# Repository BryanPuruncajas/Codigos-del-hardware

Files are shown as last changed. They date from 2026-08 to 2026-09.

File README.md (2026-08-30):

# mi-blimp-mio — Manual técnico completo del proyecto de tesis

**Estado revisado:** 30 de agosto de 2026  
**Plataforma principal:** Seeed Studio XIAO ESP32-S3  
**Comunicación de tierra:** ESP32 Base Station por USB ↔ ESP-NOW ↔ XIAO ESP32-S3  
**Visión:** Arduino Nicla Vision con OpenMV/MicroPython  
**Sensores activos:** BNO085/BNO086 + BMP390 + batería + Nicla Vision  
**Actuadores:** 2 motores brushless con ESC + 2 servos K-Power P0025  
**Control:** por consola (`run_test.py`) o desde la app móvil **AeroStock** (`blimp_app/`)

---

## Guía rápida: cómo correr todo hoy

Esta sección es el punto de entrada para un día de pruebas. El detalle de cada
prueba (P00–P11, parámetros, teoría) sigue más abajo en las secciones
numeradas; esto es solo la secuencia de arranque.

### Paso 0 — una sola vez

```powershell
# Firmware (necesita PlatformIO CLI instalado)
cd firmware
pio run

# Ground station (Python)
cd ../groundstation
pip install -r requirements.txt

# App AeroStock (solo si vas a compilarla vos; si ya está instalada en el
# celular, salteá esto)
cd ../blimp_app
flutter pub get
```

### Paso 1 — subir firmware

```powershell
cd firmware
pio run -t upload
pio device monitor -b 115200   # anotá la MAC que imprime al bootear
```

```powershell
cd ../base_station
pio run -t upload
pio device monitor -b 115200   # anotá la MAC de la base (BASE_MAC,...)
```

### Paso 2 — configurar `groundstation/user_parameters.py`

```python
robot_macs = ["AA:BB:CC:DD:EE:FF"]   # la MAC que imprimió el XIAO
SERIAL_PORT = "COM7"                 # el COM de la BASE STATION, no el del XIAO
```

Esto lo usan **tanto** `run_test.py` como `telemetry_bridge.py` (la app usa este mismo archivo).

### Paso 3A — controlar por consola

```powershell
cd groundstation
python run_test.py p01 --seconds 30
```

Ver la sección **23. run_test.py** más abajo para la lista completa de pruebas y parámetros.

### Paso 3B — controlar desde la app AeroStock

1. Cerrá cualquier Monitor Serial abierto (Arduino/PlatformIO) — si no, el bridge no puede abrir el COM.
2. Arrancá el bridge:
   ```powershell
   cd groundstation
   python telemetry_bridge.py COM7
   ```
   Sin `--dev-token` usa `changeme` por default, que es el mismo valor que trae
   "quemado" `AppConfig.devToken` en la app — no hace falta que coincidas nada a mano.
   Vas a ver en consola dónde está grabando el CSV de esta corrida.
3. Conseguí la IP de la laptop (`ipconfig`, buscá la IPv4 de la red WiFi). El celular tiene que estar en la **misma red**.
4. En la app: **Modo desarrollador** → ícono de red (⚙️) → poné la IP → **Conectar**. El chip de arriba tiene que decir **"Dev"** (si dice "solo viewer", el token no coincide).
5. Paneles disponibles en Modo desarrollador:

   | Panel | Equivale a | Para qué |
   |---|---|---|
   | **Misión** | `run_test.py p08/p09/p10/p11` | Lanzar una misión completa (armado automático + parámetros) |
   | **Panel de control** | `run_test.py p04/p05` | Altura sola / altura+yaw |
   | **Control manual** | `run_test.py p02` | D-pad: mantener presionado mueve, soltar vuelve a neutro |
   | **Banco de pruebas** | `run_test.py p00` / `p00m` | Servos sueltos (con presets Vertical/Avance/Retroceso) y motores con potencia manual, con confirmación explícita antes de armar brushless |

   Las gráficas de altura/yaw en vivo (actual vs referencia) y el track de
   globos visitados están siempre visibles arriba de estos paneles.
6. **Sin hardware a mano:** desde el home, "Vista previa (demo)" recorre toda
   la interfaz con datos simulados — útil para mostrar la app o revisar un
   diseño sin encender nada.

El CSV se graba automático en `logs/` tanto si controlás por consola como por
la app — mismo formato en los dos casos, `python analyze.py <archivo>.csv` funciona igual.

---

## 1. Objetivo del proyecto

El proyecto controla un blimp/bicóptero de tesis capaz de:

1. medir altura, orientación y velocidad angular;
2. recibir detecciones visuales desde una Nicla Vision;
3. controlar dos motores brushless y dos servos tilt;
4. comunicarse con una estación base por ESP-NOW;
5. ejecutar pruebas incrementales P00–P11;
6. evolucionar hacia una misión autónoma de visita de **4 globos visualmente idénticos**.

La filosofía actual es validar primero cada subsistema de forma aislada y luego combinarlos.

---

# 2. Estructura del repositorio

```text
mi-blimp-mio/
├── README.md
├── CHANGELOG.md
├── base_station/
│   ├── platformio.ini
│   └── src/main.cpp
├── calibration/
│   ├── gaussian_manual.py
│   ├── gaussian_manual_multi.py
│   └── colors/
│       ├── red.txt
│       └── purple.txt
├── docs/
│   ├── ARCHITECTURE.md
│   ├── PROJECT_TREE.txt
│   └── TEST_SEQUENCE.md
├── firmware/
│   ├── platformio.ini
│   ├── src/
│   │   ├── main.cpp
│   │   ├── app/
│   │   ├── mission/
│   │   └── tests/
│   └── lib/BlimpSwarm/
├── groundstation/
│   ├── run_test.py
│   ├── user_parameters.py
│   ├── common/
│   └── tests/
├── legacy/
├── logs/
└── vision/
    ├── get_gains.py
    └── perception_subsystem.py
```

### Carpetas importantes

| Carpeta | Función |
|---|---|
| `firmware/` | Firmware del XIAO ESP32-S3 montado en el blimp. |
| `base_station/` | Firmware de la ESP32 conectada al PC por USB. |
| `groundstation/` | Scripts Python para mandar comandos, armar, ejecutar pruebas y guardar telemetría. |
| `vision/` | Código MicroPython/OpenMV de la Nicla Vision. |
| `calibration/` | Datos y scripts para calibración estadística de colores. |
| `logs/` | CSV generados automáticamente por `run_test.py` o `telemetry_bridge.py` (mismo formato). |
| `mission/` | Máquina de estados P08–P11. |
| `legacy/` | Código heredado/no activo conservado como referencia. |

---

# 3. Hardware del blimp

## 3.1 XIAO ESP32-S3

El firmware principal utiliza:

```ini
[env:seeed_xiao_esp32s3]
platform = espressif32
board = seeed_xiao_esp32s3
framework = arduino
monitor_speed = 115200
upload_speed = 921600
```

Dependencias principales:

- ESP32Servo
- IBusBM
- Adafruit BMP3XX
- Adafruit BusIO
- Adafruit Unified Sensor
- SparkFun BNO08x Arduino Library

---

## 3.2 Pinout actual

Fuente: `firmware/src/app/AppConfig.h`.

| Función | Pin XIAO S3 |
|---|---:|
| Servo 1 | D0 |
| Servo 2 | D1 |
| RST BNO085/BNO086 | D2 |
| I2C SDA | D4 |
| I2C SCL | D5 |
| Nicla TX esperado | D6 |
| Nicla RX esperado | D7 |
| ADC batería | D8 |
| Brushless / ESC 1 | D9 |
| Brushless / ESC 2 | D10 |

### D2

`D2` está reservado para el reset del BNO.

Al arrancar:

```cpp
pinMode(D2, OUTPUT);
digitalWrite(D2, HIGH);
```

No reutilizar D2 para servos, motores u otra señal.

---

# 4. Calibración física de servos y vectores de empuje

Servos utilizados: **K-Power P0025**.

Configuración nominal:

| Ángulo lógico | PWM |
|---:|---:|
| 0° | 900 µs |
| 60° | 1500 µs |
| 120° | 2100 µs |

Conversión activa:

```text
0..120°  <=>  900..2100 µs
```

## 4.1 Orientaciones físicas validadas

Estas posiciones ya fueron probadas físicamente:

| Movimiento | Servo 1 | Servo 2 |
|---|---:|---:|
| Vector vertical +Z | 35° | 95° (era 85°, corregido el 23/08 por desalineación de la góndola izquierda) |
| Avance | 120° | 0° |
| Retroceso | 0° | 120° |
| Giro derecha / horario | 120° | 120° |
| Giro izquierda / antihorario | 0° | 0° |

Vista frontal usada durante las pruebas:

- Servo 1: lado izquierdo.
- Servo 2: lado derecho.

Convención de yaw observada físicamente:

- giro horario → yaw disminuye;
- giro antihorario → yaw aumenta;
- yaw trabaja en radianes dentro del firmware y envuelve en `[-π, +π]`.

---

# 5. Motores brushless y ESC

## 5.1 Escala de potencia actual

**Importante:** el código fuente actual tiene:

```cpp
ABSOLUTE_MOTOR_POWER_LIMIT = 1.00f;
motorPowerLimit = 1.00f;
```

Por tanto:

```text
0.00 = 0 %
0.10 = 10 %
0.20 = 20 %
1.00 = 100 % de la escala heredada
```

La documentación vieja que dice “límite duro de 50 %” está desactualizada.

## 5.2 Configuración de los ESC

En `RawBicopter::startup()`:

```cpp
motor1 = new BLMotor(1100, 2000, 0, D9, 55);
motor2 = new BLMotor(1100, 2000, 0, D10, 58);
```

La secuencia de ARM reproduce el comportamiento efectivo del firmware viejo:

1. habilita servos y ESC;
2. manda throttle mínimo;
3. mantiene aproximadamente throttle mínimo durante ~3.7 s;
4. termina con motores en 0 %;
5. recién después `actuatorsArmed = true`.

No existe auto-arm al encender.

---

# 6. Seguridad de arranque

Al boot:

- D2 se pone HIGH para liberar el BNO.
- pines de motores y servos comienzan en alta impedancia;
- los actuadores permanecen desarmados;
- no se ejecuta calibración automática de ESC;
- para mover motores se necesita un ARM explícito.

`SAFE_STOP` tiene modo `0`.

Cuando `run_test.py` termina o recibe `Ctrl+C`, intenta:

```text
STOP + DISARM
```

enviando varias veces el modo seguro.

> Seguridad eléctrica: el software no evita por sí mismo un posible backfeed desde USB/rail de alimentación. Verificar alimentación físicamente cuando se trabaja con batería desconectada.

---

# 7. Sensores del XIAO ESP32-S3

## 7.1 BMP390

El BMP390:

- usa I2C;
- oversampling temperatura: 8X;
- oversampling presión: 16X;
- filtro IIR: coeficiente 7;
- ODR configurado: 100 Hz;
- la rutina de actualización efectiva limita lecturas aproximadamente a 50 Hz (`20 ms`).

### Calibración de cero de altura al boot

Al iniciar:

1. descarta 5 lecturas;
2. toma 10 lecturas;
3. promedia la altitud barométrica;
4. guarda ese promedio como `groundLevel`.

La telemetría de altura es:

```text
altura = altitud barométrica - groundLevel
```

Por eso cada reinicio redefine el cero barométrico.

La velocidad vertical se calcula a partir del cambio de altitud y luego SensorSuite aplica suavizado.

---

## 7.2 BNO085/BNO086

Bus I2C:

```text
SDA = D4
SCL = D5
RST = D2 HIGH
I2C = 400 kHz después de conectar
```

### Dirección configurada actualmente

El código intenta:

```cpp
myIMU.begin(0x4A, Wire)
```

Por tanto el firmware actual espera **0x4A**.

Si el módulo físico está configurado a `0x4B`, este código debe modificarse o el sensor no será detectado.

### Datos utilizados

El firmware usa el reporte:

```text
Gyro Integrated Rotation Vector
```

y obtiene:

- roll;
- pitch;
- yaw;
- velocidad angular X;
- velocidad angular Y;
- velocidad angular Z.

---

# 8. Mapa completo de sensores

`SensorMap.h`:

| Índice | Variable |
|---:|---|
| 0 | temperature |
| 1 | altitude |
| 2 | vertical_velocity |
| 3 | roll |
| 4 | pitch |
| 5 | yaw |
| 6 | roll_rate |
| 7 | pitch_rate |
| 8 | yaw_rate |
| 9 | reservado |
| 10 | battery |
| 11 | nicla_flag |
| 12 | nicla_x |
| 13 | nicla_y |
| 14 | nicla_w |
| 15 | nicla_h |
| 16 | nicla_x_value |
| 17 | nicla_y_value |
| 18 | nicla_w_value |
| 19 | nicla_h_value |
| 20 | nicla_distance |

No existe ultrasonido en la ruta activa actual.

---

# 9. Nicla Vision

## 9.1 Qué hace realmente el “entrenamiento”

Actualmente **no se entrena una red neuronal**.

La detección de globos usa:

- imagen RGB565;
- espacio de color LAB;
- grilla 14 × 21;
- estadísticas de `A` y `B`;
- modelo gaussiano 2D;
- distancia de Mahalanobis;
- filtro probabilístico por celdas;
- seguimiento temporal.

El proceso llamado “entrenamiento” en este proyecto consiste en:

1. capturar muchos pares `(A, B)` del color del globo;
2. calcular media;
3. calcular matriz de covarianza;
4. invertir la covarianza;
5. copiar la media y matriz inversa a `COLOR_DATA`.

---

## 9.2 Configuración actual de imagen

En `vision/perception_subsystem.py`:

```python
FRAME_SIZE = sensor.HQVGA
```

Para Nicla:

```text
240 × 160 px
```

Centro horizontal usado por el control:

```text
x_center = 120 px
```

Grilla:

```text
N_ROWS = 14
N_COLS = 21
```

Objetivo actual:

```python
COLOR_TARGET = {"red": (255, 0, 0)}
```

Por tanto la misión actual busca **globos rojos**.

---

## 9.3 Parámetros actuales del detector rojo

Para Nicla:

```python
R_GAIN, G_GAIN, B_GAIN = [91, 64, 92]
```

Datos gaussianos activos para rojo:

```text
media [A, B]:
[50.173846153846156, 25.426923076923078]

matriz inversa de covarianza:
[
  [ 0.01470976874406989, -0.029273398296275985],
  [-0.029273398296275982, 0.08279564686512679]
]
```

Estos valores coinciden con los **2600 puntos válidos** presentes actualmente en:

```text
calibration/colors/red.txt
```

---

# 10. Cargar código en la Nicla Vision

El código está escrito para el firmware OpenMV/MicroPython de la Nicla Vision.

Archivo principal:

```text
vision/perception_subsystem.py
```

## Flujo recomendado

1. Instalar OpenMV IDE.
2. Conectar la Nicla Vision por USB.
3. Abrir OpenMV IDE.
4. Conectar la cámara desde el botón de conexión.
5. Si no entra correctamente al firmware OpenMV:
   - hacer doble pulsación rápida del botón RESET para entrar al bootloader/DFU;
   - permitir que OpenMV IDE actualice/cargue el firmware compatible.
6. Abrir:
   ```text
   vision/perception_subsystem.py
   ```
7. Ejecutarlo primero desde el IDE.
8. Verificar framebuffer y consola.
9. Cuando esté validado, guardar/copiar el script como:
   ```text
   /flash/main.py
   ```
   para que arranque automáticamente después de un reinicio completo.

La Nicla con OpenMV ejecuta `main.py` en un arranque frío.

---

# 11. Calibrar ganancias RGB de la Nicla

Archivo:

```text
vision/get_gains.py
```

Objetivo: obtener ganancias RGB estables para las condiciones reales de iluminación.

## Procedimiento

1. Conecta la Nicla a OpenMV IDE.
2. Coloca el globo bajo la iluminación de prueba.
3. Ejecuta:
   ```text
   vision/get_gains.py
   ```
4. Espera la estabilización automática.
5. En la consola aparecerá algo similar a:
   ```text
   RGB gain: [R, G, B]
   ```
6. Repite en condiciones representativas.
7. Si decides cambiar la calibración, actualiza en:
   ```python
   R_GAIN, G_GAIN, B_GAIN = [...]
   ```
   dentro de `perception_subsystem.py`.

Actualmente:

```python
[91, 64, 92]
```

---

# 12. Capturar datos de color para recalibrar un globo

En:

```text
vision/perception_subsystem.py
```

cambiar temporalmente:

```python
PRINT_CORNER = True
```

Como el código define:

```python
PLOT_METRIC = not PRINT_CORNER
```

esto activa el modo de recolección.

## Procedimiento recomendado

1. Deja el color objetivo visible bajo una iluminación realista.
2. Activa:
   ```python
   PRINT_CORNER = True
   ```
3. Ejecuta el script en OpenMV.
4. La imagen marca una pequeña región de recolección.
5. Coloca la superficie del globo dentro de esa región.
6. La consola imprime pares:
   ```text
   (A, B), (A, B), ...
   ```
7. Captura muestras en:
   - distintas distancias;
   - distintos ángulos;
   - varias zonas del globo;
   - iluminación clara;
   - iluminación tenue;
   - fondo real del experimento.
8. Copia los pares del globo rojo en:
   ```text
   calibration/colors/red.txt
   ```
9. Al terminar, vuelve a:
   ```python
   PRINT_CORNER = False
   ```

---

# 13. Calcular la nueva distribución de color en PC

Dependencias para calibración:

```powershell
pip install numpy matplotlib
```

Desde la carpeta:

```powershell
cd calibration
```

ejecutar:

```powershell
python gaussian_manual_multi.py
```

Para cada archivo existente imprime:

```text
mean and Inverted Covariance:
[media_A, media_B], [[...], [...]]
```

Los dos valores que interesan son:

1. media;
2. covarianza inversa.

Luego se copian en:

```python
COLOR_DATA = {
    "red": [
        [media_A, media_B],
        [[c00, c01], [c10, c11]]
    ]
}
```

dentro de `vision/perception_subsystem.py`.

### Nota del ZIP actual

`gaussian_manual_multi.py` intenta abrir:

```text
green.txt
purple.txt
blue.txt
red.txt
```

pero el ZIP actual solo contiene:

```text
purple.txt
red.txt
```

El rojo sí está sincronizado con `COLOR_DATA`.

El archivo `purple.txt` actual produce aproximadamente:

```text
media = [16.2885, -10.1674]
```

pero `COLOR_DATA["purple"]` contiene otros valores más antiguos. Actualmente no afecta la misión porque `COLOR_TARGET` solo usa rojo.

---

# 14. Comunicación Nicla ↔ XIAO

La Nicla transmite una trama tipo iBus de 32 bytes a:

```text
115200 baud
```

La Nicla usa:

```python
UART("LP1", baudrate=115200)
```

En el comentario del código:

```text
Nicla P1 = TX
Nicla P0 = RX
```

El diseño del XIAO reserva:

```text
D6 = TX
D7 = RX
```

Cableado esperado:

```text
Nicla TX (P1) -> XIAO RX (D7)
Nicla RX (P0) <- XIAO TX (D6)
GND            -> GND
```

### Nota de implementación

`AppConfig.h` define D6/D7, pero `Nicla.cpp` crea `HardwareSerial(0)` y llama `begin(..., -1, -1)`, por lo que no pasa explícitamente D6/D7 a `HardwareSerial`.

Como la comunicación ya fue observada funcionando en P06, el montaje actual está operativo, pero conviene limpiar esto después para que el pinout quede explícito en el código.

---

# 15. Formato de datos de la Nicla

Para globo:

```text
[flag, x_roi, y_roi, w_roi, h_roi,
 x_value, y_value, w_value, h_value, distance]
```

Actualmente `distance` se transmite como:

```text
9999
```

por tanto **no usar `nicla_distance` para navegación**.

## Flags observados

Modo globo:

```text
0x40 = 64
```

Sin detección activa:

```text
64
```

Detección válida alterna bits bajos y normalmente se observa:

```text
65
66
```

El firmware del XIAO considera detección válida cuando:

```cpp
(flag & 0x40) != 0
&&
(flag & 0x03) != 0
```

---

# 16. Firmware del XIAO ESP32-S3

## 16.1 Compilar

Desde:

```powershell
cd firmware
```

con PlatformIO CLI:

```powershell
pio run
```

## 16.2 Cargar

```powershell
pio run -t upload
```

Si existen varios puertos se puede definir temporalmente el puerto desde PlatformIO/VS Code o agregar `upload_port`.

## 16.3 Monitor serial

```powershell
pio device monitor -b 115200
```

Al arrancar debe aparecer información similar a:

```text
=== BLIMP TESIS / REFRACTOR DE PRUEBAS ===
SAFE BOOT...
ESP Board MAC Address: xx:xx:xx:xx:xx:xx
```

Guarda la MAC mostrada: esa es la **MAC del robot**, necesaria en `groundstation/user_parameters.py`.

---

# 17. Secuencia de inicialización del XIAO

El flujo actual de `setup()` es:

```text
Serial 115200
    ↓
HardwareSafety::preInit()
    ↓
D2 HIGH
motores/servos alta impedancia
    ↓
ESP-NOW
    ↓
FullBicopter::startup()
    ↓
actuadores DESARMADOS
    ↓
SensorSuite
 ├── BNO
 ├── BMP390
 └── batería
    ↓
Nicla modo 0x40 / balloon
    ↓
carga de preferencias
    ↓
SAFE_STOP
```

El loop intenta ejecutarse cada:

```text
4000 µs ≈ 250 Hz
```

aunque cada sensor/control tiene sus propias tasas efectivas.

Telemetría ESP-NOW está limitada a:

```text
10 Hz por flag
```

---

# 18. Base Station ESP32

La base **no ejecuta control de vuelo**.

Su trabajo es:

```text
PC/Python
   ↕ USB Serial 115200
ESP32 Base Station
   ↕ ESP-NOW
XIAO ESP32-S3
```

Archivo:

```text
base_station/src/main.cpp
```

## 18.1 Placa configurada actualmente

```ini
[env:esp32dev]
board = esp32dev
framework = arduino
monitor_speed = 115200
upload_speed = 921600
```

Esto corresponde a una ESP32 genérica tipo DevKit/NodeMCU.

Si la base fuera otro XIAO ESP32-S3:

```ini
board = seeed_xiao_esp32s3
```

---

# 19. Cargar la Base Station

Desde:

```powershell
cd base_station
```

Compilar:

```powershell
pio run
```

Cargar:

```powershell
pio run -t upload
```

Monitor:

```powershell
pio device monitor -b 115200
```

La base imprime:

```text
BASE_MAC,XX:XX:XX:XX:XX:XX
```

---

# 20. Configurar la Ground Station

Archivo:

```text
groundstation/user_parameters.py
```

Variables importantes:

```python
robot_macs = ["DC:B4:D9:39:B3:B4"]
SERIAL_PORT = "COM5"
```

Cambiar:

```text
robot_macs
```

por la MAC que imprime el XIAO.

Cambiar:

```text
SERIAL_PORT
```

por el COM de la **ESP32 Base Station**, no el COM del XIAO.

Ejemplo:

```python
robot_macs = ["AA:BB:CC:DD:EE:FF"]
SERIAL_PORT = "COM7"
```

El script convierte la MAC a minúsculas automáticamente.

---

# 21. Registro automático de la base en el robot

Cada ejecución normal de `run_test.py` hace:

1. agrega la MAC del robot como peer de la base;
2. envía al robot la MAC de la base;
3. el robot guarda esa MAC en NVS bajo:
   ```text
   GroundMac
   ```
4. se manda `reload=1`;
5. el XIAO vuelve a cargar `GroundMac`;
6. agrega la estación de tierra como peer;
7. comienza la telemetría.

Por eso normalmente no es necesario escribir manualmente la MAC de la base en el firmware.

---

# 22. Preparar Python

Desde:

```powershell
cd groundstation
```

Instalar:

```powershell
pip install -r requirements.txt
```

Actualmente:

```text
pyserial >= 3.5
```

Muy importante:

> Cierra el Serial Monitor de Arduino/PlatformIO antes de ejecutar Python o Windows puede devolver “Access is denied” al abrir el COM.

---

# 23. run_test.py

Forma general:

```powershell
python run_test.py TEST [opciones]
```

Tests disponibles:

```text
p00m
p00
p01
p02
p03
p04
p05
p06
p07
p08
p09
p10
p11
```

Modos internos:

| Test | Mode |
|---|---:|
| SAFE_STOP | 0 |
| P00M motores | 8 |
| P00 servos | 9 |
| P01 sensores | 10 |
| P02 manual | 11 |
| P03 yaw | 12 |
| P04 altura | 13 |
| P05 altura+yaw | 14 |
| P06 Nicla raw | 15 |
| P07 centrado visual | 16 |
| P08 un globo | 17 |
| P09 visita+escape | 18 |
| P10 dos globos | 19 |
| P11 cuatro globos | 20 |

---

# 24. Protocolo de seguridad de run_test.py

Las pruebas actuadas:

```text
P02
P03
P04
P05
P07
P08
P09
P10
P11
```

requieren escribir:

```text
ARMAR
```

El script manda el paquete de ARM incluyendo ya:

- modo;
- referencias;
- ganancias;
- parámetros auxiliares.

Después espera:

```text
4.2 s
```

para que termine la secuencia de armado de ESC.

Luego manda `reset=1` conservando las mismas referencias.

Esto evita que un paquete posterior reemplace el ARM antes de que el firmware lo procese.

---

# 25. Telemetría

La base imprime:

```text
TEL,flag,v0,v1,v2,v3,v4,v5
```

`run_test.py` lo convierte a nombres legibles.

## F1 — estado principal

```text
height
yaw
roll
pitch
battery
vertical_velocity
```

## F2 — Nicla

```text
nicla_flag
nicla_x
nicla_y
nicla_w
nicla_h
nicla_distance
```

## F3 — actuadores

```text
servo1
servo2
motor1
motor2
armed
mode
```

## F4 — control

```text
rollrate
pitchrate
yawrate
yaw_ref
height_ref
fx_cmd
```

El significado exacto de `fx_cmd` depende del test:

- P03: error de yaw;
- P04/P05: error de altura;
- misión: error visual normalizado durante APPROACH.

## F5 — misión

```text
mission_state
visited
target_count
search_height
visit_score
elapsed_s
```

---

# 26. Logs CSV

Cada ejecución de `run_test.py` **o** cada sesión de `telemetry_bridge.py`
(o sea, cada vez que controlás desde la app AeroStock) crea automáticamente:

```text
logs/blimp_YYYYMMDD_HHMMSS.csv
```

Mismo formato en los dos casos — `analyze.py` no distingue de dónde vino el log.

Columnas:

```text
pc_time
flag
name0/v0
...
name5/v5
```

Sirven para:

- ajustar PID/PD;
- medir overshoot;
- medir tiempo de subida;
- observar potencia de sostenimiento;
- analizar yaw;
- validar visión;
- validar estados de misión.

---

# 27. P00 — Calibración de servos

P00 **no habilita brushless**.

El firmware desacopla el servo no seleccionado (`detach`) para evitar que al probar uno se mueva el otro.

## Servo 1 — barrido

```powershell
python run_test.py p00 --servo 1 --servo-step 2 --servo-delay 0.06 --seconds 2
```

Escribir:

```text
SERVO
```

Secuencia:

```text
60° -> 0° -> 120° -> 60°
```

## Servo 2

```powershell
python run_test.py p00 --servo 2 --servo-step 2 --servo-delay 0.06 --seconds 2
```

## Posición fija Servo 1

```powershell
python run_test.py p00 --servo 1 --servo-angle 35 --seconds 10
```

## Posición fija Servo 2

```powershell
python run_test.py p00 --servo 2 --servo-angle 95 --seconds 10
```

## Ambos

```powershell
python run_test.py p00 --servo both --servo-angle 60 --seconds 10
```

Para diagnosticar interferencias eléctricas/mecánicas es preferible probar primero **uno por uno**.

---

# 28. P00M — Prueba directa de brushless

P00M no usa:

- PID;
- mixer;
- yaw;
- altura;
- visión.

Permite mandar directamente potencia a uno o ambos motores.

## Motor 1, vector vertical, 10 %

```powershell
python run_test.py p00m --motor 1 --power 10 --servo1-angle 35 --servo2-angle 95 --motor-seconds 3
```

## Motor 2

```powershell
python run_test.py p00m --motor 2 --power 10 --servo1-angle 35 --servo2-angle 95 --motor-seconds 3
```

## Ambos a 10 %

```powershell
python run_test.py p00m --motor both --power 10 --servo1-angle 35 --servo2-angle 95 --motor-seconds 3
```

El script pide:

```text
ARMAR
```

y luego:

```text
MOTOR
```

No empezar con potencias altas.

---

# 29. P01 — Integración de sensores

No mueve actuadores.

```powershell
python run_test.py p01 --seconds 30
```

Revisar principalmente F1:

```text
height
yaw
roll
pitch
battery
vertical_velocity
```

Y verificar:

- altura cercana al cero después de boot;
- yaw responde al giro;
- roll/pitch cambian en los ejes esperados;
- batería tiene lectura razonable;
- Vz no explota con ruido.

---

# 30. P02 — Control manual físico

```powershell
python run_test.py p02
```

Escribir:

```text
ARMAR
```

Controles:

| Tecla | Acción |
|---|---|
| `w` | avance |
| `s` | retroceso |
| `a` | giro izquierda |
| `d` | giro derecha |
| `r` | empuje +Z |
| `f` | -Z solicitado → descenso pasivo, motores 0 |
| `x` | salir |

Cada tecla se escribe y luego Enter.

P02 usa potencia fija:

```text
20 %
```

y selecciona solo el comando de mayor magnitud si por accidente llegan varios ejes.

---

# 31. P03 — Control de yaw PD

P03 controla yaw de forma aislada.

Control:

```text
error = wrapPi(yaw_ref - yaw)
```

Esfuerzo:

```text
Kp * |error| - Kd * velocidad_hacia_objetivo
```

Si corrige:

```text
potencia >= yaw_min_power
potencia <= yaw_max_power
```

Zona muerta configurable.

## Ejemplo suave

```powershell
python run_test.py p03 --yaw-deg 0 --yaw-kp 0.10 --yaw-kd 0.03 --yaw-min-power 7 --yaw-max-power 8.5 --yaw-deadband-deg 5 --seconds 60
```

Parámetros:

| Parámetro | Significado |
|---|---|
| `--yaw-deg` | setpoint absoluto de yaw en grados |
| `--yaw-kp` | ganancia proporcional |
| `--yaw-kd` | amortiguación derivativa |
| `--yaw-min-power` | potencia mínima cuando hay corrección |
| `--yaw-max-power` | límite de potencia |
| `--yaw-deadband-deg` | banda donde deja de corregir |

---

# 32. P04 — PID de altura

P04 mantiene únicamente altura.

Servos siempre:

```text
S1 = 35°
S2 = 95°
```

Control:

```text
error = Zref - Z
P = Kp * error
I = integral
D = -Kd * Vz_filtrada
```

Salida:

```text
0 .. max_power
```

No existe empuje activo hacia -Z; si está alto, el sistema reduce/corta potencia y deja descenso pasivo.

Otros detalles:

```text
deadband P = ±2.5 cm
integral activa dentro de ±35 cm
aporte integral máximo = 6 %
filtro Vz alpha = 0.82
```

## Configuración que se venía probando

```powershell
python run_test.py p04 --height -1 --kp 0.30 --ki 0.025 --kd 0.01 --max-power 12 --slew 0.18 --seconds 60
```

Cambiar `--height` por el setpoint deseado.

### Parámetros

| Parámetro | Función |
|---|---|
| `--height` | altura objetivo relativa al cero barométrico del boot |
| `--kp` | respuesta al error |
| `--ki` | aprende/aporta potencia de sostenimiento |
| `--kd` | frena según velocidad vertical |
| `--max-power` | límite máximo en % |
| `--slew` | velocidad máxima de cambio de potencia, escala 0..1/s |

Aliases equivalentes:

```text
--alt-kp
--alt-ki
--alt-kd
--alt-max-power
--alt-slew
```

Los `--alt-*` explícitos tienen prioridad sobre los nombres cortos.

---

# 33. P05 v3 — Altura primero + yaw manteniendo altura

Este es el P05 nuevo del ZIP revisado.

Arquitectura:

```text
ALTITUDE_ACQUIRE
        ↓
YAW_ACQUIRE
        ↓
HOLD
```

## Fase 0 — ALTITUDE_ACQUIRE

- solo Z tiene autoridad;
- servos permanecen en:
  ```text
  35° / 95°
  ```
- yaw es ignorado;
- altura debe quedar dentro de la banda configurada;
- además:
  ```text
  |Vz filtrada| <= 0.10 m/s
  ```
- debe mantenerse así:
  ```text
  2 segundos
  ```

Entonces cambia a `YAW_ACQUIRE`.

## Fase 1 — YAW_ACQUIRE

El control de altura **no se apaga**.

Se calculan simultáneamente:

```text
altPower
yawPower
```

El único mixer manda:

```text
outputPower = max(altPower, yawPower)
```

Los servos se interpolan desde el vector vertical hacia el vector extremo de yaw.

`--yaw-servo-authority` controla cuánto se alejan de:

```text
35° / 95°
```

Ejemplo 30 %:

```text
usa como máximo 30 % del recorrido desde Z hacia 0/0 o 120/120
```

Yaw debe permanecer dentro de la banda de éxito durante:

```text
500 ms
```

para entrar a HOLD.

## Fase 2 — HOLD

Mantiene control de altura.

Si yaw se aleja más de:

```text
yaw_success + 3°
```

vuelve a `YAW_ACQUIRE`.

---

# 34. Comando recomendado actual P05

Ejemplo:

```powershell
python run_test.py p05 --height 0 --yaw-deg 0 --kp 0.30 --ki 0.025 --kd 0.01 --alt-min-power 6 --max-power 15 --slew 0.18 --alt-success-cm 10 --yaw-kp 0.10 --yaw-kd 0.03 --yaw-min-power 7 --yaw-max-power 8.5 --yaw-success-deg 10 --yaw-servo-authority 30 --seconds 120
```

### Altura

```text
Kp              = 0.30
Ki              = 0.025
Kd              = 0.01
mínimo           = 6 %
máximo           = 15 %
slew             = 0.18 /s
éxito Z          = ±10 cm
estabilidad Vz   = ±0.10 m/s
tiempo estable   = 2 s
```

### Yaw

```text
Kp              = 0.10
Kd              = 0.03
mínimo           = 7 %
máximo           = 8.5 %
éxito            = ±10°
lock             = 500 ms
re-adquisición   = >13°
servo authority  = 30 %
```

### Debug P05

Cada ~500 ms el XIAO imprime:

```text
[P05] phase=...
zErr=...
vz=...
altP=...
yawErrDeg=...
yawP=...
out=...
S1=...
S2=...
```

Para encontrar la potencia necesaria para sostener altura, observar:

```text
altP
```

Ejemplo:

```text
altP=0.083
```

equivale aproximadamente a:

```text
8.3 %
```

---

# 35. Cuantización de parámetros P05

P05 empaqueta varios parámetros dentro de floats para no cambiar `ControlInput`.

Por eso algunos valores no tienen resolución infinita.

## Altura

- `alt-min-power`: entero en %
- `alt-max-power`: entero en %
- `slew`: pasos de 0.02/s
- `alt-success-cm`: entero en cm

## Yaw

- min/max: décimas de %
- yaw success: pasos de 0.5°
- servo authority: pasos de 10 %

Por ejemplo:

```text
--yaw-max-power 8.5
```

sí conserva 8.5 %.

---

# 36. P06 — Nicla RAW

No mueve actuadores.

```powershell
python run_test.py p06 --seconds 60
```

Mirar F2:

```text
nicla_flag
nicla_x
nicla_y
nicla_w
nicla_h
nicla_distance
```

Resultados ya observados:

```text
imagen = 240 × 160
centro x ≈ 120
x aumenta izquierda -> derecha
distance = 9999
```

Usar P06 siempre que se recalibre la visión.

---

# 37. P07 — Centrado visual

P07 gira para colocar el globo cerca del centro de la imagen.

Error:

```text
error_px = nicla_x - 120
error_norm = error_px / 120
```

Con deadband por defecto:

```text
±15 px
```

Zona central:

```text
105 .. 135 px
```

Comando:

```powershell
python run_test.py p07 --vis-kp 0.10 --vis-kd 0.015 --vis-min-power 6 --vis-max-power 10 --vis-deadband-px 15 --seconds 60
```

Si no detecta objetivo:

```text
motores = 0
```

Si está centrado:

```text
motores = 0
```

---

# 38. Estados actuales de misión P08–P11

`BalloonMission` utiliza:

```text
SEARCH = 0
APPROACH = 1
VISIT_CONFIRM = 2
ESCAPE = 3
WAIT_TARGET_LOST = 4
DONE = 5
```

Constantes actuales:

```text
centro X                   = 120 px
deadband visual default    = ±15 px
potencia avance/escape     = 20 %
P08/P09 búsqueda           = 20 %
P10/P11 búsqueda default   = 10 %
umbral visita nicla_w      = 60
frames visita              = 3
frames pérdida             = 8
escape                     = 1.8 s
separación nuevo objetivo  = 45°
```

---

# 39. P08 — Un globo

Objetivo:

```text
SEARCH
  ↓ detecta
APPROACH
  ↓ centrado + w>=60
VISIT_CONFIRM
  ↓ 3 frames
DONE
```

P08 se desarma automáticamente al terminar.

Comando:

```powershell
python run_test.py p08 --vis-kp 0.10 --vis-kd 0.015 --vis-min-power 6 --vis-max-power 10 --vis-deadband-px 15 --seconds 120
```

### Importante

P08 **no tiene supervisor de altura**.

Durante:

- SEARCH;
- giro visual;
- avance;

usa la lógica de misión original.

---

# 40. P09 — Visita + escape

Flujo:

```text
SEARCH
  ↓
APPROACH
  ↓
VISIT_CONFIRM
  ↓
ESCAPE 1.8 s
  ↓
WAIT_TARGET_LOST
  ↓ 8 frames sin objetivo
DONE
```

Comando:

```powershell
python run_test.py p09 --vis-kp 0.10 --vis-kd 0.015 --vis-min-power 6 --vis-max-power 10 --vis-deadband-px 15 --seconds 180
```

P09 también se desarma al llegar a DONE.

---

# 41. P10 — Dos globos

Objetivo:

```text
target_count = 2
```

Después de visitar uno:

```text
ESCAPE
→ WAIT_TARGET_LOST
→ 8 frames sin globo
→ SEARCH
→ acumular al menos 45° de yaw
→ aceptar siguiente detección
```

Esto existe porque la Nicla no entrega ID individual del globo.

## Comando base

**Con el código actual usar una referencia positiva mayor a 0.05 m.**

```powershell
python run_test.py p10 --height 1.00 --kp 0.30 --ki 0.025 --kd 0.01 --max-power 15 --slew 0.18 --vis-kp 0.10 --vis-kd 0.015 --vis-max-power 10 --seconds 180
```

---

# 42. P11 — Cuatro globos

Igual que P10, pero:

```text
target_count = 4
```

Comando:

```powershell
python run_test.py p11 --height 1.00 --kp 0.30 --ki 0.025 --kd 0.01 --max-power 15 --slew 0.18 --vis-kp 0.10 --vis-kd 0.015 --vis-max-power 10 --seconds 600
```

Aunque `--seconds` sea largo, la misión entra a `DONE` y se desarma cuando:

```text
visited == 4
```

---

# 43. Control de altura actual dentro de P10/P11

**P10/P11 todavía NO utilizan la arquitectura P05 v3.**

El código actual conserva un supervisor anterior.

Entra a corrección de altura cuando:

```text
está >12 cm por debajo del setpoint
o
está >18 cm por encima del setpoint
```

Sale cuando vuelve a:

```text
±7 cm
```

Mientras corrige altura:

```text
la máquina de misión queda pausada
```

Si está bajo:

```text
PID Z + servos 35/95
```

Si está alto:

```text
motores 0 -> descenso pasivo
```

Esto significa que P10/P11 todavía usan filosofía:

```text
corrección de altura con prioridad
       ↓
reanudar misión
```

y **no todavía**:

```text
Z + yaw + avance simultáneos mediante mixer
```

Ese será el siguiente cambio arquitectónico después de terminar de validar P05.

---

# 44. Parámetros de visión en P10/P11

Por falta de campos libres en `ControlInput`, P10/P11 reciben:

```text
vis Kp
vis Kd
vis max power
```

pero actualmente mantienen fijos:

```text
vis min power = 6 %
deadband      = ±15 px
```

Aunque `run_test.py` acepte `--vis-min-power` y `--vis-deadband-px`, esos dos valores **no se transmiten a P10/P11** en la implementación actual.

Para P07/P08/P09 sí son configurables.

---

# 45. Secuencia recomendada de validación

No saltar directamente a P11.

Orden recomendado:

```text
P00  -> calibrar servos
P00M -> validar ESC/motores
P01  -> sensores
P02  -> movimientos físicos
P03  -> yaw aislado
P04  -> altura aislada
P05  -> altura + yaw mediante mixer
P06  -> Nicla RAW
P07  -> centrado visual
P08  -> un globo
P09  -> visita + escape
P10  -> dos globos
P11  -> cuatro globos
```

Con la nueva arquitectura prevista:

```text
P05 validado
   ↓
actualizar BalloonMission
   ↓
ALTITUDE_ACQUIRE
   ↓
SEARCH manteniendo Z
   ↓
ALIGN manteniendo Z
   ↓
APPROACH: Z + yaw/visión + avance
   ↓
VISIT
   ↓
ESCAPE
   ↓
RECOVER
   ↓
SEARCH siguiente globo
```

---

# 46. Parámetros principales — resumen rápido

## Altura

| Opción | Uso |
|---|---|
| `--height` | setpoint Z |
| `--kp` / `--alt-kp` | proporcional |
| `--ki` / `--alt-ki` | integral |
| `--kd` / `--alt-kd` | derivativa |
| `--max-power` / `--alt-max-power` | potencia máxima |
| `--slew` / `--alt-slew` | rampa de potencia |
| `--alt-min-power` | P05: piso de potencia |
| `--alt-success-cm` | P05: banda de adquisición |

## Yaw

| Opción | Uso |
|---|---|
| `--yaw-deg` | referencia absoluta |
| `--yaw-kp` | proporcional |
| `--yaw-kd` | derivativa |
| `--yaw-min-power` | mínimo de giro |
| `--yaw-max-power` | máximo de giro |
| `--yaw-deadband-deg` | P03 |
| `--yaw-success-deg` | P05 |
| `--yaw-servo-authority` | P05: cuánto inclina servos desde el vector Z |

## Visión

| Opción | Uso |
|---|---|
| `--vis-kp` | proporcional visual |
| `--vis-kd` | derivativa visual |
| `--vis-min-power` | mínimo de giro |
| `--vis-max-power` | máximo de giro |
| `--vis-deadband-px` | banda centrada |

---

# 47. Diagnóstico rápido

## No llega telemetría

Revisar:

1. COM correcto de la base;
2. Serial Monitor cerrado;
3. MAC del robot correcta;
4. base y robot encendidos;
5. ejecutar nuevamente `run_test.py` para registrar/reload GroundMac.

## `Access is denied` en Windows

Cerrar:

- Serial Monitor;
- Arduino IDE monitor;
- PlatformIO monitor;
- cualquier terminal que tenga abierto el COM.

## BNO no aparece

Buscar:

```text
Ooops, no BNO085 detected
```

Revisar:

- D2 HIGH;
- SDA D4;
- SCL D5;
- alimentación;
- dirección actual esperada `0x4A`.

## BMP390 no aparece

Buscar:

```text
Could not find a valid BMP390 sensor
```

Revisar I2C y alimentación.

## Nicla siempre da flag 64

Revisar:

- script `perception_subsystem.py` ejecutándose;
- target rojo;
- iluminación;
- UART cruzada TX↔RX;
- tierra común;
- `COLOR_DATA`;
- ganancias RGB;
- usar P06.

## `nicla_distance=9999`

Es normal en el modo globo actual.

## Motor pita pero no gira

Revisar:

- secuencia ARM completa;
- esperar 4.2 s;
- batería;
- ESC;
- potencia mínima física;
- P00M para aislar el problema.

---

# 48. Estado actual y pendientes detectados al revisar este ZIP

Esta sección es importante para no confundir “lo que queremos” con “lo que el código hace hoy”.

## 48.1 README viejo dice 50 %, código actual dice 100 %

Documentos antiguos contienen:

```text
brushless limitados a 50 %
```

pero el fuente actual usa:

```text
1.00 = 100 %
```

Este README usa el valor real del fuente actual.

---

## 48.2 P05 fuente actual es más nuevo que `firmware.bin`

Dentro de `.pio/build` existe un `firmware.bin`, pero su fecha es anterior al `P05YawAltitude.cpp` v3.

Por tanto:

> **No asumir que ese `firmware.bin` contiene P05 v3.**

Recompilar el proyecto antes de cargar la versión actual.

---

## 48.3 P10/P11 no están migrados a P05 v3

P05 ya usa:

```text
ALTITUDE_ACQUIRE -> YAW_ACQUIRE -> HOLD
```

con mixer.

P10/P11 todavía usan `BalloonMission.cpp` con supervisor de altura prioritario.

---

## 48.4 P10/P11 ignoran altura 0 o negativa

En `BalloonMission::reset()`:

```cpp
requestedHeight > 0.05f
```

es condición para aceptar `--height`.

Por tanto actualmente:

```text
--height 1.0  -> sí se usa
--height 0    -> se ignora
--height -1   -> se ignora
```

Si se ignora, usa la altura medida al iniciar la misión.

Esto debe corregirse antes de usar referencias cero/negativas en P10/P11.

P04 y P05 no tienen esta restricción.

---

## 48.5 `run_test.py --help` tiene un error de formato

La lógica de ejecución compila con Python, pero el `--help` actual puede fallar por un `%` sin escapar dentro de un texto de ayuda de argparse.

Los comandos normales siguen funcionando.

Pendiente: reemplazar `%` por `%%` en los textos de ayuda correspondientes.

---

## 48.6 Mensaje de P00M sobre el “barrido”

El texto de consola de `run_test.py` todavía menciona un “barrido simultáneo”.

Sin embargo el `RawBicopter::setActuatorsArmed()` actual reproduce el efecto real del firmware viejo:

```text
throttle mínimo durante ~3.7 s
```

No una rampa real de potencia.

---

## 48.7 D6/D7 de Nicla no están pasados explícitamente al UART

`AppConfig.h` los reserva, pero `Nicla.cpp` usa:

```cpp
MySerial0.begin(115200, SERIAL_8N1, -1, -1);
```

Como P06 ha funcionado físicamente, no es un bloqueo actual, pero conviene hacerlo explícito para robustez y documentación.

---

## 48.8 BNO solo intenta 0x4A

Si se cambia el módulo o strap de dirección, agregar intento a 0x4B o hacer dirección configurable.

---

## 48.9 Calibración de colores incompleta para multi-color

`gaussian_manual_multi.py` espera 4 archivos.

Solo existen:

```text
red.txt
purple.txt
```

Actualmente no importa porque el objetivo activo es solo rojo.

---

## 48.10 Purple no está sincronizado

El archivo `purple.txt` y el `COLOR_DATA["purple"]` actual no corresponden a la misma distribución.

No afecta al target rojo actual.

---

# 49. Qué archivos son “fuente de verdad” ahora

Para configuración de hardware:

```text
firmware/src/app/AppConfig.h
```

Para mapa de sensores:

```text
firmware/src/app/SensorMap.h
```

Para modos:

```text
firmware/src/tests/TestModes.cpp
groundstation/tests/modes.py
```

Para P03:

```text
firmware/src/tests/P03YawControl.cpp
```

Para P04:

```text
firmware/src/tests/P04AltitudeControl.cpp
```

Para P05 actual:

```text
firmware/src/tests/P05YawAltitude.cpp
```

Para visión:

```text
vision/perception_subsystem.py
```

Para P08–P11:

```text
firmware/src/mission/BalloonMission.cpp
firmware/src/mission/BalloonMission.h
```

Para comandos:

```text
groundstation/run_test.py
```

Para COM/MAC:

```text
groundstation/user_parameters.py
```

---

# 50. Checklist antes de una prueba de vuelo

```text
[ ] Firmware recompilado con los fuentes actuales
[ ] Base Station cargada
[ ] COM correcto
[ ] MAC correcta
[ ] Serial Monitor cerrado
[ ] Nicla ejecutando perception_subsystem.py
[ ] Nicla detecta rojo en P06
[ ] BNO responde en P01
[ ] BMP390 calibró cero al boot
[ ] Servos verificados con P00
[ ] ESC verificados con P00M
[ ] Orientaciones físicas no cambiaron
[ ] Batería segura
[ ] Zona libre
[ ] Blimp asegurado para pruebas iniciales
[ ] Potencias bajas al comenzar
[ ] Logs habilitados
```

---

# 51. Flujo de desarrollo recomendado a partir de este estado

Actualmente el paso lógico es:

1. terminar de validar P05 v3;
2. obtener un rango real de `altP` que mantenga sustentación;
3. validar cuánto `yaw-servo-authority` permite girar sin perder Z;
4. guardar ganancias finales de P04/P05;
5. migrar `BalloonMission` a la arquitectura por fases;
6. agregar adquisición de altura antes de SEARCH;
7. mantener Z durante SEARCH;
8. crear ALIGN separado;
9. después agregar APPROACH con tilt de avance;
10. caracterizar compensación vertical por tilt;
11. dejar Roll inicialmente como variable de seguridad;
12. solo después considerar control activo de Roll.

Arquitectura objetivo:

```text
CALIBRATION / ALTITUDE_ACQUIRE
             ↓
           SEARCH
             ↓
            ALIGN
             ↓
 APPROACH (Z + Yaw + X)
             ↓
       VISIT_CONFIRM
             ↓
           ESCAPE
             ↓
     WAIT_TARGET_LOST
             ↓
      ALTITUDE_RECOVER
             ↓
           SEARCH
             ↓
       visited == 4
             ↓
            DONE
```

---

# 52. Resumen de comandos más usados

## Sensores

```powershell
python run_test.py p01 --seconds 30
```

## Servo 1 a 35°

```powershell
python run_test.py p00 --servo 1 --servo-angle 35 --seconds 10
```

## Servo 2 a 95°

```powershell
python run_test.py p00 --servo 2 --servo-angle 95 --seconds 10
```

## Motores 10 % vertical

```powershell
python run_test.py p00m --motor both --power 10 --servo1-angle 35 --servo2-angle 95 --motor-seconds 3
```

## Manual

```powershell
python run_test.py p02
```

## Yaw

```powershell
python run_test.py p03 --yaw-deg 0 --yaw-kp 0.10 --yaw-kd 0.03 --yaw-min-power 7 --yaw-max-power 8.5 --yaw-deadband-deg 5 --seconds 60
```

## Altura

```powershell
python run_test.py p04 --height -1 --kp 0.30 --ki 0.025 --kd 0.01 --max-power 12 --slew 0.18 --seconds 60
```

## Altura + yaw P05 v3

```powershell
python run_test.py p05 --height 0 --yaw-deg 0 --kp 0.30 --ki 0.025 --kd 0.01 --alt-min-power 6 --max-power 15 --slew 0.18 --alt-success-cm 10 --yaw-kp 0.10 --yaw-kd 0.03 --yaw-min-power 7 --yaw-max-power 8.5 --yaw-success-deg 10 --yaw-servo-authority 30 --seconds 120
```

## Nicla RAW

```powershell
python run_test.py p06 --seconds 60
```

## Centrado visual

```powershell
python run_test.py p07 --vis-kp 0.10 --vis-kd 0.015 --vis-min-power 6 --vis-max-power 10 --vis-deadband-px 15 --seconds 60
```

## Un globo

```powershell
python run_test.py p08 --vis-kp 0.10 --vis-kd 0.015 --vis-min-power 6 --vis-max-power 10 --vis-deadband-px 15 --seconds 120
```

## Visita + escape

```powershell
python run_test.py p09 --vis-kp 0.10 --vis-kd 0.015 --vis-min-power 6 --vis-max-power 10 --vis-deadband-px 15 --seconds 180
```

## Dos globos — estado actual

```powershell
python run_test.py p10 --height 1.00 --kp 0.30 --ki 0.025 --kd 0.01 --max-power 15 --slew 0.18 --vis-kp 0.10 --vis-kd 0.015 --vis-max-power 10 --seconds 180
```

## Cuatro globos — estado actual

```powershell
python run_test.py p11 --height 1.00 --kp 0.30 --ki 0.025 --kd 0.01 --max-power 15 --slew 0.18 --vis-kp 0.10 --vis-kd 0.015 --vis-max-power 10 --seconds 600
```

---

## Fin

Este README representa el estado del código fuente revisado el **17-08-2026**.  
Antes de cambiar la arquitectura de P10/P11, conservar esta versión como punto de recuperación.

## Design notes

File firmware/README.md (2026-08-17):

# Firmware XIAO ESP32-S3

Un único firmware contiene P01–P11. `main.cpp` arranca siempre desarmado y despacha el modo recibido por ESP-NOW.

Puntos fijos de hardware: D2=RST BNO (HIGH), D0/D1=servos, D9/D10=brushless. El límite duro de motores es 50%.
## Hardware de sensores activo (tesis)

Esta version NO usa GY-US42V2/ultrasonico. La ruta activa contiene:
- BNO085/BNO086 por I2C (D2 reservado como RST, D4 SDA, D5 SCL).
- BMP390 por I2C.
- Monitor de bateria por D8 (divisor de la PCB).
- Nicla Vision por UART como subsistema de percepcion.

Por ello la Nicla comienza en `sensors[11]` y el arreglo completo tiene 21 valores.

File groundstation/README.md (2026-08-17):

# Ground station

1. Ajusta `user_parameters.py`.
2. `pip install -r requirements.txt`
3. Empieza con `python run_test.py p01 --seconds 30`.

Pruebas con movimiento exigen escribir `ARMAR`. Para P03/P05 usa `--yaw-deg`; para P04/P05 usa `--height`.

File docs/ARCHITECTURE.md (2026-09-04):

# Arquitectura de mi-blimp-mio

**Para:** capítulo de análisis/diseño de la tesis.
**Alcance:** explica CÓMO funciona cada pieza del sistema y POR QUÉ está diseñada así — no es un manual de uso (eso es el `README.md` raíz), es la arquitectura interna.

---

## 0. Panorama general

El sistema tiene **cinco subsistemas** que se comunican entre sí:

```text
┌─────────────────┐   UART iBus 32B    ┌──────────────────────┐
│  Nicla Vision    │ ─────────────────► │  XIAO ESP32-S3       │
│  (percepción)    │   115200 baud      │  (firmware, "cerebro")│
└─────────────────┘                    └───────────┬──────────┘
                                                     │ ESP-NOW (radio 2.4GHz)
                                                     │ paquetes ControlInput (13 floats)
                                        ┌────────────▼──────────┐
                                        │  ESP32 Base Station    │
                                        │  (puente Serial↔radio) │
                                        └────────────┬───────────┘
                                                      │ USB Serial 115200
                                       ┌──────────────┴───────────────┐
                                       │                               │
                              ┌────────▼────────┐          ┌──────────▼─────────┐
                              │  run_test.py     │          │ telemetry_bridge.py │
                              │  (CLI, un test    │          │ (WebSocket, sesión  │
                              │   a la vez)       │          │  larga, multi-cliente)│
                              └───────────────────┘          └──────────┬──────────┘
                                                                          │ WebSocket
                                                               ┌──────────▼──────────┐
                                                               │  App AeroStock       │
                                                               │  (Flutter, celular)  │
                                                               └──────────────────────┘
```

Dos caminos de control **paralelos e independientes** llegan al mismo firmware:
la consola (`run_test.py`) y la app (a través de `telemetry_bridge.py`). Nunca
corren los dos a la vez porque ambos abren el mismo puerto Serial de la base
station. El firmware no distingue de dónde vino el comando — para él, todo
comando es un mismo tipo de paquete (`ControlInput`).

---

## 1. Hardware y su rol

| Componente | Rol | Por qué esa elección |
|---|---|---|
| **XIAO ESP32-S3** | Corre el firmware principal: lee sensores, ejecuta el lazo de control a ~250 Hz, decide qué actuar. | Dual-core 240 MHz, tamaño/peso mínimos (crítico en un blimp: cada gramo es sustentación que hay que generar). |
| **BNO085/086** | IMU: da roll/pitch/yaw absolutos y velocidades angulares vía fusión de sensores integrada en el chip (no hay que fusionar acelerómetro+giroscopio+magnetómetro en el firmware). | Delegar la fusión al chip ahorra ciclos de CPU y evita reimplementar un filtro de Kalman/Madgwick. |
| **BMP390** | Barómetro: altura relativa al punto de arranque (se recalibra el "cero" en cada boot). | Un blimp no puede usar un rango-láser/ultrasonido de forma confiable con una envolvente de tela moviéndose cerca; el barómetro es inmune a eso. |
| **Nicla Vision** | Corre OpenMV/MicroPython, detecta el color del globo, manda `[flag, x, y, w, h, ...]` por UART. | Desacopla el procesamiento de imagen (pesado) del lazo de control (que necesita determinismo a 250 Hz) — si la visión se cuelga o tarda, el control sigue corriendo. |
| **2× motor brushless + ESC** | Generan el empuje. | Mucho mejor relación peso/empuje que motores DC con escobillas. |
| **2× servo K-Power P0025** | Inclinan cada motor (nacela) para vectorizar el empuje entre "arriba" y "adelante/atrás/giro". | Con solo 2 actuadores de dirección (no 4 como un dron), el vector de empuje de CADA motor cubre tanto sustentación como traslación/rotación — más simple y liviano que agregar actuadores dedicados por eje. |
| **ESP32 "Base Station"** | Puente Serial(USB)↔ESP-NOW. No ejecuta ninguna lógica de vuelo. | El PC no tiene radio ESP-NOW; la base es solo un adaptador de protocolo. |

**Pinout activo** (fuente de verdad: `firmware/src/app/AppConfig.h`): D0/D1 servos,
D2 reset del BNO (reservado, NUNCA reusar), D4/D5 I2C, D6/D7 UART Nicla, D8 ADC
batería, D9/D10 ESC.

---

## 2. Arquitectura del firmware

### 2.1 Capas (de abajo hacia arriba)

```text
lib/BlimpSwarm/          <- librería heredada del proyecto original (Lehigh
  robot/                    University, "BlimpSwarm"/"MochiSwarm"). Clases de
    Robot.h (interfaz)       bajo nivel: Robot es la interfaz abstracta,
    RawBicopter               RawBicopter implementa actuadores+ESC+servos
    FullBicopter              crudos, FullBicopter le agrega sensores (BNO,
                               BMP, Nicla) y un control() heredado (poco usado
                               por este proyecto, que prefiere mandar
                               comandos ya resueltos vía commandMotorPowerTest/
                               commandServoCalibrationUs).
  act/                      AServo, BLMotor: wrappers de PWM (ESP32Servo).
  sense/                    NiclaSuite, BNO/BMP wrappers.
  comm/                     BaseCommunicator + LLC_ESPNow: abstrae el
                             transporte (podría cambiarse por otro radio
                             sin tocar el resto).

src/app/                 <- capa de aplicación de ESTE proyecto (no heredada)
  AppConfig.h                Constantes: pines, modos, calibración P0025,
                              índices de ControlInput.
  AppContext.h                El "estado global": robot, comm, sensores,
                               comando actual, modo actual.
  ControlCommon.h              NÚCLEO DE CONTROL compartido: PID de altura,
                               cascada de yaw, geometría de servos, mixer,
                               y (nuevo) la asignación analítica de empuje.
  Telemetry.cpp                Arma y manda las 5 tramas de telemetría.
  HardwareSafety.h              Secuencia de boot seguro (D2 HIGH, PWM en
                               alta impedancia, sin auto-arm).

src/tests/                <- una prueba = un archivo, P00 a P07
  TestModes.cpp               Dispatcher: mode -> función de test.
  P0X....cpp                   Cada P0X-P07 es relativamente independiente
                               (usa ControlCommon pero no BalloonMission).

src/mission/              <- P08-P11 comparten UNA sola máquina de estados
  BalloonMission.cpp/h        SEARCH -> APPROACH -> VISIT_CONFIRM -> ESCAPE
                               -> WAIT_TARGET_LOST -> (siguiente globo o DONE)

src/main.cpp              <- setup()/loop(): pega todo. Ver 2.2.
```

**Por qué esta separación:** el proyecto empezó (ver `legacy/`) como un
firmware monolítico donde cada prueba tenía su propia copia de las
ganancias/geometría — sintonizar en una prueba no servía para la siguiente.
La refactorización a `app/ControlCommon.h` compartido es la decisión de
diseño más importante del firmware: **una sola fuente de verdad para
constantes de control**, así lo que se sintoniza en P03/P04/P05 se hereda
automáticamente en P07 y en la misión.

### 2.2 El bucle principal (`main.cpp`)

```cpp
void loop() {
    processCommands();                 // ¿llegó un ControlInput nuevo? aplicarlo
    app.sensorCount = app.robot->sense(app.sensors);   // leer BNO+BMP+batería+Nicla
    TestModes::run(app);               // ejecutar la lógica del modo actual
    // esperar hasta completar CONTROL_LOOP_US (~4000us => ~250 Hz)
}
```

Tres cosas importantes de este diseño:

1. **Un solo `ControlInput` en vuelo.** No hay cola de comandos: el paquete
   más reciente reemplaza al anterior. Esto es intencional — en control en
   tiempo real no querés estar ejecutando comandos viejos.
2. **`processCommands()` es el único lugar que arma/desarma o cambia de
   modo.** Cualquier cambio de modo pasa por `TestModes::onModeEnter()`,
   que resetea integrales/estado — evita que P05 arranque con el integral
   de yaw contaminado de una prueba anterior.
3. **El período del lazo es fijo, no reactivo.** Aunque `TestModes::run()`
   tarde menos, se espera hasta completar los 4 ms. Esto le da al
   controlador un `dt` predecible, necesario para que las ganancias PID
   sintonizadas en un test sigan siendo válidas en otro.

### 2.3 El protocolo `ControlInput` (13 floats)

```text
[0]  MODE     -- qué prueba/modo ejecutar
[1]  FX       -- fuerza horizontal deseada (según el modo)
[2]  FZ       -- fuerza vertical deseada / altura objetivo (según el modo)
[3]  TX       -- (varía según modo)
[4]  TZ       -- (varía según modo, frecuentemente yaw objetivo)
[5..9]  AUX0..AUX4  -- 5 huecos genéricos, su significado depende del modo
[10] ARM      -- >0.5 arma, <-0.5 desarma
[11] RELOAD   -- releer preferencias NVS
[12] RESET    -- reinicia el estado del modo actual sin cambiar de modo
```

**Por qué "genérico" y no un struct por modo:** cambiar el firmware para
agregar un campo específico a cada prueba habría significado tocar el
protocolo de radio cada vez. En cambio, cada prueba interpreta AUX0-AUX4 a
su manera (documentado en cada archivo `PXX....cpp`) — el costo es que hay
que leer el código fuente de cada prueba para saber qué significa cada
AUX, pero la ventaja es que el protocolo de transporte nunca cambió desde
P00 hasta P11.

**El problema de los 9 huecos y P05:** P05 necesita 2 referencias + 6
ganancias + 8 límites — mucho más que 9 floats. La solución (ver
`groundstation/common/control_pack.py`) fue empaquetar varios límites
enteros pequeños dentro de UN SOLO float usando manipulación de bits
(`pack_alt`/`pack_yaw`), con un bit marcador de versión para detectar si
el firmware recibe un paquete del formato viejo. Esto es un patrón de
diseño clásico de sistemas embebidos con ancho de banda de mensaje fijo.

### 2.4 Modelo de control: geometría del bicóptero

Cada servo va de `Z_DEG` (vector vertical) a un extremo (`FORWARD_DEG`,
`BACK_DEG`, `LEFT_DEG` o `RIGHT_DEG`, según el eje que se esté
comandando). La función central es:

```cpp
computeEfficiencies(servo1Deg, servo2Deg, etaZ, etaYaw)
  phi1 = servo1 - SERVO1_Z_DEG
  phi2 = SERVO2_Z_DEG - servo2        // signo invertido: montaje espejado
  etaZ   = 0.5*(cos(phi1) + cos(phi2))   // fracción de la potencia que es empuje vertical
  etaYaw = 0.5*(|sin(phi1)| + |sin(phi2)|) // fracción que es empuje lateral
```

Esta es la pieza matemática que conecta "ángulo de servo" con "cuánta
sustentación real estoy generando" — sin ella, cualquier controlador que
incline los servos para girar o avanzar perdería sustentación sin que el
lazo de altura lo supiera compensar.

**`SERVO2_Z_DEG` no es una constante arbitraria: es una calibración física.**
La góndola izquierda tiene ~10° de desalineación mecánica de fábrica/montaje.
En vuelo (23/08) se midió que con `SERVO2_Z_DEG=85°` el blimp giraba solo
(~28°/s) incluso con ambos motores a la misma potencia — la asimetría
generaba un par de yaw permanente. Subiendo a 95° el ascenso sale limpio.
Esto ilustra un punto de análisis importante: **una constante de "geometría
ideal" en el código en realidad está compensando una imperfección de
fabricación real**, y por eso el propio código deja anotado "pendiente:
confirmar si el óptimo es exactamente 95, o enderezar la góndola
mecánicamente" — la compensación por software es un parche, no la
solución de fondo.

### 2.5 Lazo de altura (PID)

```text
error = Zref - Z
P = Kp * error
I = integral condicional (se congela fuera de una zona de ±1.5 m, anti-windup)
D = -Kd * Vz_filtrada   (Vz viene de un filtro exponencial, alpha=0.82,
                          porque derivar la altura cruda amplifica ruido)
salida = clamp(P + I + D, 0, maxPower)
```

Sin empuje activo hacia -Z (el diseño asume que si hay exceso de altura,
alcanza con bajar potencia y dejar que el descenso sea pasivo por la
física del sistema — no está validado un empuje activo hacia abajo).

### 2.6 Cascada de yaw

Es una cascada de DOS lazos, no un PD simple:

```text
lazo EXTERNO: error de ángulo (rad) -> velocidad angular deseada (rad/s)
              (con el error truncado a 36° para no pedir velocidades
               absurdas ante errores grandes)
lazo INTERNO: error de velocidad -> mando de potencia (PID sobre el
              giroscopio, no sobre el ángulo)
```

**Por qué cascada y no un PD directo sobre el ángulo:** un blimp tiene MUCHA
inercia rotacional y CASI NADA de amortiguamiento aerodinámico en yaw
(constante de tiempo medida ~125 s). Un PD directo sobre el ángulo con
ganancias que no saturan tarda demasiado en asentarse; controlando
velocidad angular en el lazo interno se logra un amortiguamiento mucho más
fuerte y predecible (las ganancias documentadas, `DEF_YAW_KD=9.0`, se
llegaron a esa magnitud sintonizando explícitamente contra ese
amortiguamiento aerodinámico casi nulo).

### 2.7 El mixer: de "dos lazos" a "dos servos + dos motores"

`mixOutputs()` combina la demanda de altura y el mando de yaw en un solo
comando físico:

```text
blend = f(yawCmd)                          // hacia qué lado y cuánto inclinar
servo1,servo2 = interpolar(Z, LEFT/RIGHT, blend)
etaZ, etaYaw = computeEfficiencies(servo1, servo2)
pAlt = altitudeDemand / etaZ               // potencia para sostener altura A PESAR del tilt
pYaw = interpolación de potencia según |yawCmd|
potencia_final = max(pAlt, pYaw)           // ninguno de los dos lazos se queda sin actuador
```

Este mixer usa la MISMA potencia para los dos motores (solo varía el
ángulo del servo). Fue suficiente para P03-P07, pero tenía una limitación
real que se descubrió en la fase de avance de la misión:

### 2.8 La asignación analítica de empuje (`computeThrustAllocation`, nueva)

**El problema que resolvió:** en la fase de avance de `APPROACH`
(BalloonMission), el diseño original inclinaba los servos a una fracción
FIJA (0.50) del recorrido hacia "avance completo", y después intentaba
compensar la sustentación perdida subiendo la potencia. El problema: a
blend=0.50 la eficiencia vertical real es ~0.71 — el 71% de la potencia
del motor sigue siendo empuje vertical aunque la intención sea "avanzar".
Combinado con un piso de potencia fijo (`MOVE_POWER=0.20`), el blimp
generaba más sustentación de la necesaria mientras avanzaba y **subía en
vez de mantenerse nivelado**.

**La solución** está tomada directamente del modelo de control del paper
en el que se basa este proyecto — *MochiSwarm: A testbed for robotic
blimps in realistic environments* (Xu et al., 2025, arXiv:2503.03077),
ecuaciones (4), (5), (9)-(11) — que resuelve el problema de asignación de
empuje de forma cerrada en vez de por prueba y error:

```text
dado: fx (empuje horizontal deseado), fz (empuje vertical deseado)
potencia = sqrt(fx² + fz²)
ángulo_desde_vertical = atan2(|fx|, fz)     // 0 = puro vertical, 90° = puro horizontal
```

Con esto, el ángulo de servo y la potencia YA NO se fijan de antemano —
se calculan exactamente para la combinación de avance+altura que se pide
en cada instante. Con `fx=0` el resultado es matemáticamente idéntico al
vector vertical de siempre (cero regresión); con `fx>0` el sistema
inclina "lo justo y necesario", nunca más. Además prioriza la altura sobre
el avance si la potencia disponible no alcanza para ambos (recortando el
avance, nunca la sustentación) — el mismo criterio de seguridad que ya
usaba `mixOutputs`.

**Punto de análisis para la tesis:** esto es un buen ejemplo de la
diferencia entre una heurística ajustada empíricamente (fracción fija +
compensación de potencia) y una solución de forma cerrada derivada del
modelo dinámico del vehículo — la heurística "funciona" dentro de un rango
limitado de operación, pero desperdicia autoridad de control fuera de ese
rango; la solución analítica generaliza sin necesidad de volver a ajustar
constantes a mano.

---

## 3. Percepción visual (Nicla Vision)

`vision/perception_subsystem.py` corre en la Nicla bajo OpenMV/MicroPython.
**No hay red neuronal ni "entrenamiento" en el sentido de machine learning
supervisado** — el pipeline es:

```text
imagen RGB565
  -> espacio de color LAB
  -> grilla 14x21 celdas
  -> por celda: distancia de Mahalanobis de (A,B) a una gaussiana 2D
     ajustada al color del globo (media + matriz de covarianza inversa)
  -> filtro probabilístico temporal por celda (creencia bayesiana simple,
     no un solo frame)
  -> blob más grande que pasa el filtro de forma (circular/rectangular)
  -> [flag, x_roi, y_roi, w_roi, h_roi, x, y, w, h, distancia=9999] por UART
```

"Entrenar" significa: capturar muchos pares (A,B) del color real del globo
bajo distintas condiciones de luz/ángulo/distancia, calcular su media y
matriz de covarianza (`calibration/gaussian_manual_multi.py`, en la PC), y
copiar esos dos números a `COLOR_DATA` en el script de la Nicla. Es
clasificación estadística clásica (distancia de Mahalanobis a una
distribución gaussiana), no aprendizaje profundo — una elección deliberada
dado el presupuesto de cómputo de la Nicla y la necesidad de correr a
~10 Hz de forma determinística.

**`nicla_distance` siempre vale 9999** — es un campo del protocolo que
existía cuando el proyecto tenía un sensor ultrasónico (retirado, ver
`legacy/unused_sensors/`); se dejó el campo relleno en vez de romper el
formato de mensaje de 10 valores. El proxy real de "qué tan cerca estoy"
que usa la misión es el ancho del blob (`nicla_w`), no la distancia.

---

## 4. Comunicación

### 4.1 Nicla -> XIAO

UART tipo iBus, 32 bytes, 115200 baud, ~10 Hz. Un solo sentido
(Nicla->XIAO); el XIAO puede mandar un byte de vuelta para cambiar de modo
(0x40 = modo globo).

### 4.2 XIAO <-> Base Station

ESP-NOW (radio 2.4 GHz de bajo nivel de Espressif, sin necesidad de
router/AP — por eso "sin infraestructura externa", un requisito del propio
paper de MochiSwarm para operar en campo). El paquete es el
`ControlInput` de 13 floats descrito en 2.3, mandado desde la base hacia
el robot; la telemetría va en sentido inverso.

### 4.3 Base Station <-> PC

Serial USB, 115200 baud. La base es un traductor puro Serial<->ESP-NOW: no
interpreta el contenido de los paquetes, solo los pasa. Formato de
telemetría desde la base hacia el PC (texto plano, fácil de parsear y de
inspeccionar a ojo en un monitor serie):

```text
TEL,flag,v0,v1,v2,v3,v4,v5
```

5 "flags" (grupos de 6 valores) rotan a 10 Hz cada uno: F1 altura/actitud/
batería, F2 Nicla, F3 actuadores, F4 control (ganancias/errores), F5
misión.

### 4.4 PC <-> App (WebSocket, `telemetry_bridge.py`)

Este es el puente que se agregó para que la app móvil pudiera controlar el
robot sin reimplementar el protocolo de la base station en Dart. Rol:

```text
Serial (mismo protocolo que run_test.py)
   <-> telemetry_bridge.py (asyncio, un solo proceso)
   <-> WebSocket ws://<ip-laptop>:8765
   <-> N clientes (viewers de solo lectura + como máximo un "dev" con permiso de comando)
```

Decisiones de diseño clave:

- **Un solo lector de Serial** (`read_loop`), compartido por todos los
  clientes vía `broadcast()`. Si cada cliente abriera su propia conexión
  Serial, se pisarían.
- **Los comandos se escriben directo al Serial sin esperar el ACK de
  vuelta** — si el bridge esperara una línea de respuesta después de cada
  comando, competiría con `read_loop` por las mismas líneas entrantes y
  ambos leerían basura del otro. El efecto del comando se confirma por la
  telemetría normal (ej. el campo `armed` cambiando), no por un ACK
  síncrono.
- **Roles viewer/dev por token**, no por usuario/contraseña — suficiente
  para un dispositivo de laboratorio en una red de confianza, evitando la
  complejidad de un sistema de autenticación real.
- **`common/control_pack.py` es compartido bit a bit con `run_test.py`**:
  ambos importan las mismas funciones de empaquetado, así que un comando
  mandado desde la app y el mismo comando mandado por consola producen el
  IDÉNTICO paquete de bytes. Esto evitó un bug real de este proyecto: la
  primera versión de la app tenía su propia lógica de armado de paquetes,
  desincronizada de la de `run_test.py`, y mandaba valores a índices AUX
  equivocados.

---

## 5. Ground station (Python)

| Archivo | Rol |
|---|---|
| `common/link.py` | `BlimpLink`: abre el Serial, arma/lee paquetes `ControlInput` crudos. Es la única pieza que sabe el formato binario exacto. |
| `common/telemetry.py` | Parsea líneas `TEL,...` a un objeto `Telemetry(flag, values)` + `LABELS` (nombre de cada campo por flag). |
| `common/csv_logger.py` | Escribe cada `Telemetry` recibido a un CSV con nombres de columna legibles. |
| `common/control_pack.py` | El empaquetador de bits (`pack_alt`/`pack_yaw`) y el armador de payload por modo (`build_control_payload`) — la lógica de protocolo más delicada del proyecto, ahora compartida entre CLI y bridge. |
| `run_test.py` | CLI interactiva: un test por invocación, valida parámetros, arma con confirmación tecleada, corre el test, desarma al salir. |
| `telemetry_bridge.py` | Servidor WebSocket de sesión larga para la app (ver 4.4). |
| `analyze.py` | Post-procesamiento offline de un CSV: gráficas de altura/yaw/servos/motores para ajustar ganancias. |

**Por qué la CLI valida tanto (rangos, cuantización) y el bridge menos:**
`run_test.py` es la herramienta de un humano tecleando comandos sueltos —
tiene sentido rechazar valores fuera de rango con un mensaje claro. El
bridge recibe comandos ya generados por la UI de la app (que ya limita los
sliders a rangos válidos), así que su validación es más liviana; los
límites "duros" de seguridad (potencia, ángulos) siguen estando en las
funciones de empaquetado compartidas, no en cada punto de entrada por
separado.

---

## 6. App móvil (AeroStock, Flutter)

```text
lib/
  main.dart                 MaterialApp + tema
  core/theme/app_theme.dart Paleta y ThemeData centralizados
  models/telemetry_message.dart   Parseo del JSON de telemetría
  services/telemetry_service.dart  EL ESTADO DE LA APP (ChangeNotifier):
                                     conexión WebSocket, telemetría acumulada,
                                     historial para gráficas, modo demo,
                                     y todos los métodos de comando (arm,
                                     startMission, setServo, etc.)
  screens/
    home_screen.dart         Landing: viewer / dev / demo
    viewer_screen.dart        Solo lectura
    dev_screen.dart            Todos los paneles de control (misión,
                                 P04/P05, P02 manual, banco de pruebas P00/P00M)
  widgets/
    telemetry_widgets.dart     Gráficas, chips de estado, track de globos
    aerostock_logo.dart          Marca
    institution_footer.dart      Logos ESPOL/FIMCP
```

**Patrón de estado: un único `TelemetryService` (ChangeNotifier) inyectado
a cada pantalla**, no un gestor de estado más pesado (Provider/Bloc/Riverpod).
Justificado por el tamaño de la app: un solo flujo de datos (telemetría) y
un puñado de comandos, sin necesidad de composición de estado compleja.

**Por qué el modo demo genera datos localmente en vez de grabar una sesión
real:** permite iterar el diseño de la interfaz (gráficas, layout,
animaciones) sin tener el hardware encendido, y sirve como demostración
para terceros (comité de tesis, por ejemplo) sin depender de que el blimp
esté armado y en el aire en ese momento.

**Un detalle de Flutter con impacto real en este proyecto:** los paneles
con controles de texto (`_MissionPanel`, `_ControlPanel`, `_BenchTestPanel`,
`_ManualControlPanel`) usan `AutomaticKeepAliveClientMixin`. Sin eso, al
vivir dentro de una lista scrolleable, Flutter destruye y recrea el widget
cuando sale de pantalla — perdiendo cualquier valor tecleado. Es un detalle
de implementación, pero ilustra un problema real de UI con listas
virtualizadas que vale la pena documentar si la tesis discute la app.

---

## 7. Máquina de estados de misión (`BalloonMission`, P08-P11)

```text
        ┌─────────┐  ve un globo  ┌───────────┐  centrado y cerca  ┌───────────────┐
        │ SEARCH  ├──────────────►│ APPROACH  ├────────────────────►│ VISIT_CONFIRM │
        └────▲────┘               └─────┬─────┘                    └───────┬───────┘
             │                          │ pierde el globo                  │ 3 frames confirmando
             │                          ▼                                  ▼
             │                      SEARCH                            ┌─────────┐
             │                                                        │ ESCAPE  │ (1.8 s, aleja del globo)
             │  8 frames sin ver nada, y ya giró >45°                 └────┬────┘
             │                                                             ▼
             │                                                   ┌──────────────────┐
             └───────────────────────────────────────────────────┤ WAIT_TARGET_LOST │
                                                                   └──────────────────┘
```

`visited==target_count` desde `WAIT_TARGET_LOST` -> `DONE` (desarma solo).

**Por qué el ciclo completo por cada globo, en vez de "detectar todos y
visitarlos en orden":** la Nicla no entrega un ID por globo (todos son
idénticos a propósito, parte del enunciado del problema). No hay forma de
saber si el globo que se ve ahora es "el mismo de antes" — por eso, tras
visitar uno, hay que alejarse (ESCAPE), esperar a perderlo de vista
(WAIT_TARGET_LOST) y girar al menos 45° antes de aceptar una nueva
detección como "el siguiente globo". Es una solución de bajo costo
sensorial a un problema de identificación que normalmente se resolvería
con visión más sofisticada (tracking con re-identificación) o con un
sensor adicional.

**P10/P11 todavía usan un supervisor de altura de prioridad distinto al
resto:** cuando el error de altura es grande, la misión se pausa por
completo y un lazo separado corrige antes de retomar — a diferencia de
P08/P09, que corrigen altura y persiguen el globo de forma simultánea todo
el tiempo. Es una decisión de robustez tomada para 2-4 globos (más tiempo
de vuelo total = más oportunidades de que la altura se desvíe mucho), no
una limitación técnica del mixer.

---

## 8. Flujo de datos end-to-end (ejemplo: lanzar P08 desde la app)

```text
1. App: usuario configura Kp/Ki/Kd/altura/potencia en el panel de Misión,
   toca "Iniciar misión".
2. App -> bridge (WebSocket): {"cmd":"mission_start","test":"p08", height:..., kp:..., ...}
3. bridge: llama common.control_pack.build_control_payload() -- LA MISMA
   función que usa run_test.py -- arma fx/fz/tx/tz/aux (con ALT_PACK/
   YAW_PACK empaquetados en bits donde corresponde).
4. bridge -> Serial: escribe 'C' + MAC + 13 floats (arm=1).
5. Base station: recibe por USB, reenvía por ESP-NOW al XIAO.
6. XIAO (processCommands): ve PARAM_ARM>0.5, arma actuadores; ve que el
   modo pedido (P08) es distinto al actual, llama TestModes::onModeEnter
   -> BalloonMission::configure(1,true) + reset().
7. bridge espera 4.2 s (tiempo real que tarda la secuencia de ARM del ESC).
8. bridge -> Serial: mismo paquete pero con reset=1 (arranca limpio,
   conservando las ganancias ya mandadas).
9. XIAO (loop, ~250 Hz): sense() lee BNO+BMP+Nicla; TestModes::run()
   despacha a BalloonMission::update(); la maquina de estados corre
   SEARCH -> ... segun lo que vea la Nicla; Telemetry:: manda F1-F5 por
   ESP-NOW a 10 Hz cada una.
10. Base station: reenvia la telemetria por USB como texto "TEL,flag,...".
11. bridge: parsea cada linea, la agrega al CSV de logs/, y la reenvia por
    WebSocket a todos los clientes conectados (broadcast).
12. App: TelemetryService recibe el JSON, actualiza el estado, notifica a
    los widgets -> las graficas y el track de globos se redibujan.
```

Este mismo flujo, sin los pasos 2-4 y 7-8 (o sea, sin el bridge en el
medio), es exactamente lo que hace `run_test.py p08 ...` por consola —
por diseño, los dos caminos convergen al mismo protocolo desde el paso 4
en adelante.

---

## 9. Resumen de decisiones de diseño (para la sección de análisis)

| Decisión | Alternativa descartada | Por qué |
|---|---|---|
| Protocolo `ControlInput` genérico de 13 floats | Un mensaje por tipo de comando | Simplicidad del transporte a costa de tener que documentar el significado de AUX por modo |
| Empaquetado de bits para límites (ALT_PACK/YAW_PACK) | Ampliar `ControlInput` | No romper el protocolo de radio ya validado en vuelo |
| Clasificación gaussiana + Mahalanobis para color | Red neuronal / clasificador entrenado | Presupuesto de cómputo de la Nicla y necesidad de determinismo a ~10 Hz |
| Cascada de yaw (velocidad interna, ángulo externo) | PD directo sobre el ángulo | Inercia rotacional alta + amortiguamiento aerodinámico casi nulo |
| Asignación analítica de empuje (MochiSwarm eqs.) | Blend fijo + compensación de potencia | El blend fijo desperdiciaba componente vertical fuera de su punto de ajuste; la solución cerrada generaliza |
| Reidentificación de globos por "girar 45° + timeout" | Tracking visual con ID persistente | La Nicla no distingue globos idénticos entre sí; esto evita necesitar hardware/visión adicional |
| Un solo `TelemetryService` compartido en la app | Gestor de estado más pesado (Bloc/Riverpod) | Un solo flujo de datos, la complejidad no se justifica |
| CLI y app comparten `control_pack.py` | Cada cliente arma su propio paquete | Evitó (y evita a futuro) que los dos caminos de control queden desincronizados |

---

## Referencias

- Xu, J., Vu, T., D'Antonio, D. S., & Saldaña, D. (2025). *MochiSwarm: A
  testbed for robotic blimps in realistic environments*. arXiv:2503.03077.
  — Modelo de dinámica/control del bicóptero (ecs. 4,5,9-11) y arquitectura
  de hardware en la que se basa este proyecto.
- BlimpSwarm (Lehigh University, AIRLab) — librería de robot/actuadores
  original de la que parte `firmware/lib/BlimpSwarm/`.

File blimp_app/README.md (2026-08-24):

# blimp_app

A new Flutter project.

## Getting Started

This project is a starting point for a Flutter application.

A few resources to get you started if this is your first Flutter project:

- [Learn Flutter](https://docs.flutter.dev/get-started/learn-flutter)
- [Write your first Flutter app](https://docs.flutter.dev/get-started/codelab)
- [Flutter learning resources](https://docs.flutter.dev/reference/learning-resources)

For help getting started with Flutter development, view the
[online documentation](https://docs.flutter.dev/), which offers tutorials,
samples, guidance on mobile development, and a full API reference.

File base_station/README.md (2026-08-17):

# Base station

Puente genérico USB Serial ↔ ESP-NOW. No ejecuta control de vuelo. La telemetría se imprime como `TEL,flag,v0,v1,v2,v3,v4,v5`.

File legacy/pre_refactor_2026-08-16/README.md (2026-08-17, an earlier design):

# Snapshot previo al refactor

Estos archivos son copia exacta de los puntos principales recibidos antes del refactor de pruebas. No se compilan en el proyecto nuevo.

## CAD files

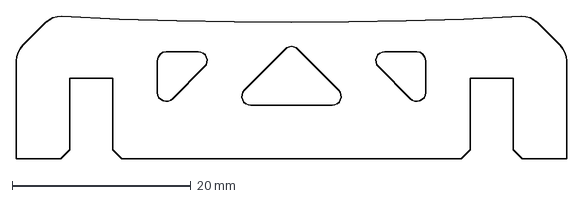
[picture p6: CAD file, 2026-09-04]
ESTRUCTURA 3D CARTON PLUMA/CORTE LASER/SOP. SUPERIOR X2.dxf
61.6 x 16.0 mm

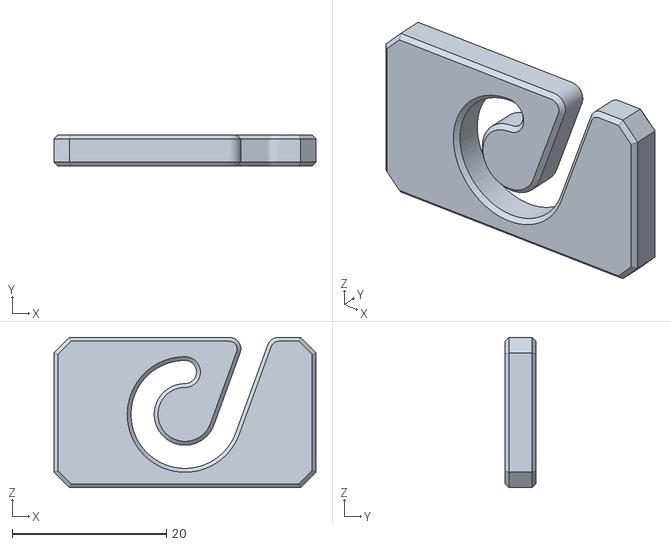
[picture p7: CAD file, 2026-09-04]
ESTRUCTURA 3D CARTON PLUMA/IMPRESION 3D/SOPORTE PEGADO v1.stl
34.0 x 4.00 x 19.5

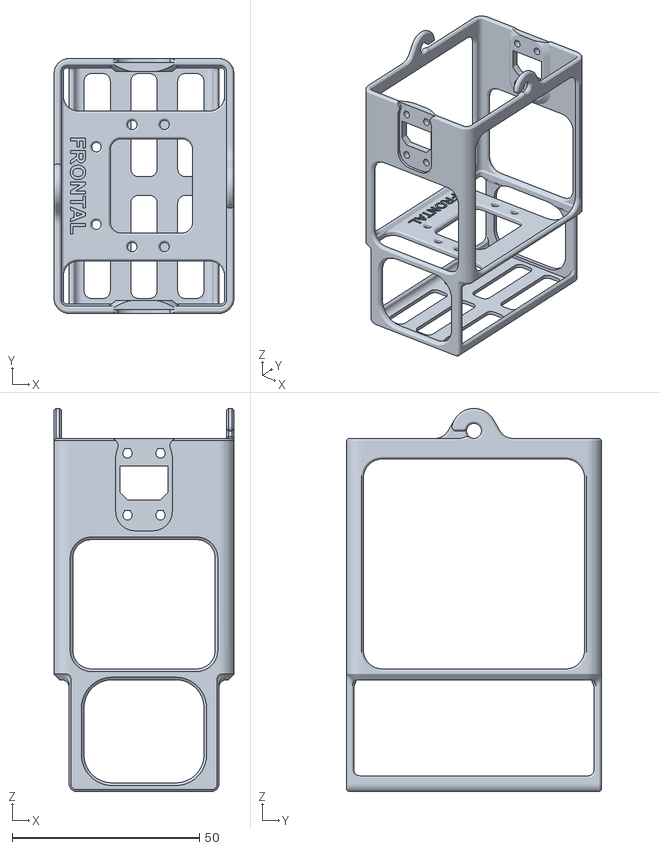
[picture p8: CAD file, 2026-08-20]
ESTRUCTURA 3D/STLs/ESTRUCTURA 3D v28.stl
48.0 x 68.0 x 102.2

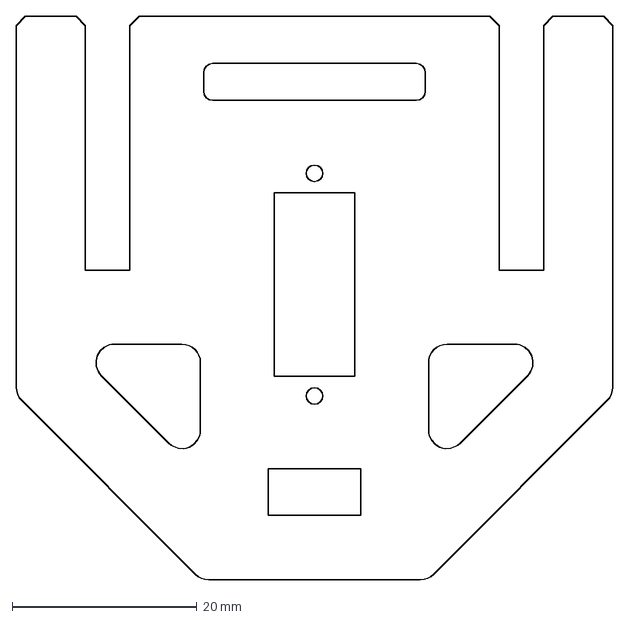
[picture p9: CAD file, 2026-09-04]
ESTRUCTURA 3D CARTON PLUMA/CORTE LASER/SOP. SERVOS X2.dxf
64.6 x 61.0 mm

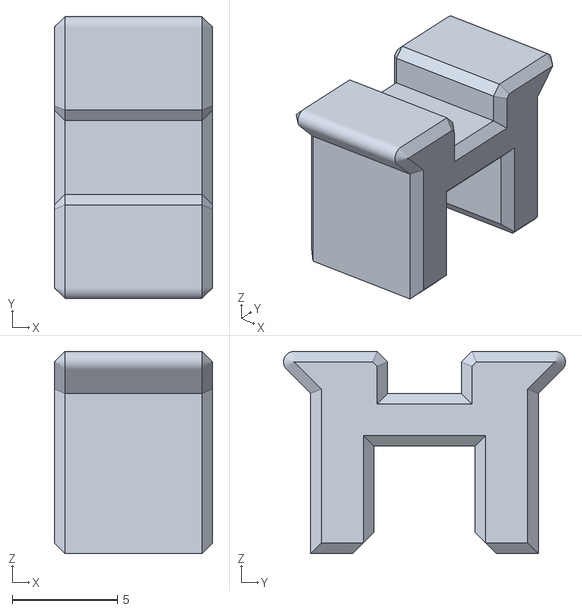
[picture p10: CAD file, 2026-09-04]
ESTRUCTURA 3D CARTON PLUMA/IMPRESION 3D/SEGUROS MOTORES v3.stl
7.50 x 13.4 x 9.60

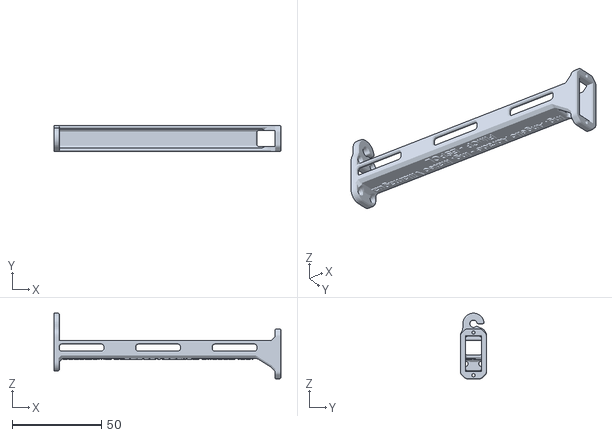
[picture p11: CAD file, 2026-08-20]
ESTRUCTURA 3D/STLs/BRAZO IMPRESO v19.stl
127.5 x 14.8 x 36.9

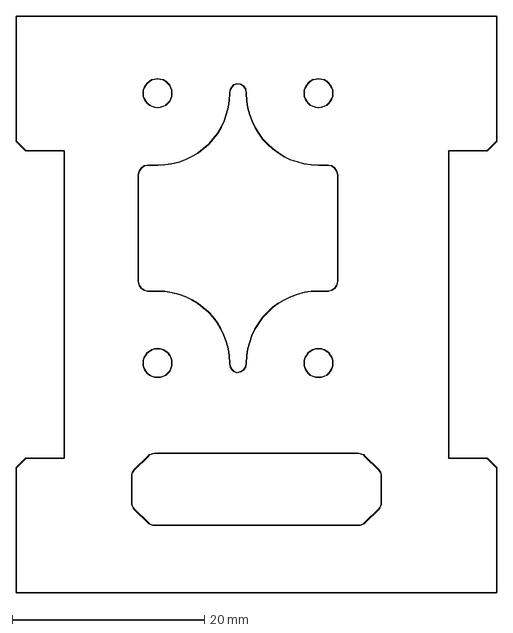
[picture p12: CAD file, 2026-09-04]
ESTRUCTURA 3D CARTON PLUMA/CORTE LASER/SOPORTE PLACAS.dxf
50.0 x 60.0 mm

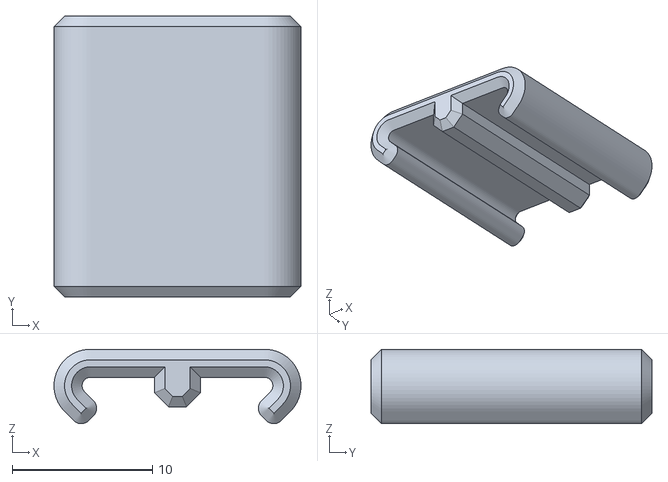
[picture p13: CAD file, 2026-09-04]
ESTRUCTURA 3D CARTON PLUMA/IMPRESION 3D/SEGUROS MOTORES 2 v2.stl
17.6 x 20.0 x 5.30

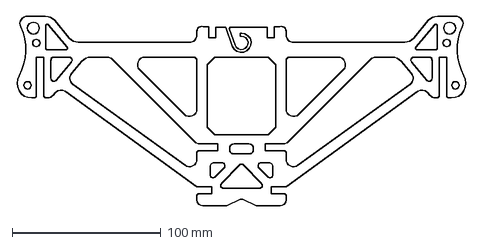
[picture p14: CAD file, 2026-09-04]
ESTRUCTURA 3D CARTON PLUMA/CORTE LASER/FRAME P X2.dxf
303.0 x 127.5 mm

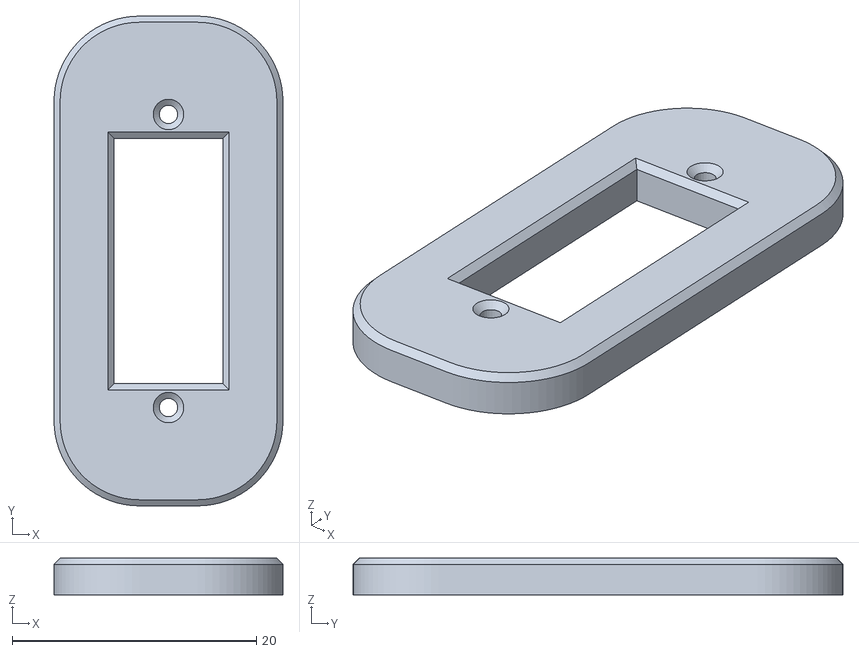
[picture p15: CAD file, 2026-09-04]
ESTRUCTURA 3D CARTON PLUMA/IMPRESION 3D/SOPORTE PLASTICO SERVO v1.stl
18.8 x 40.1 x 3.00

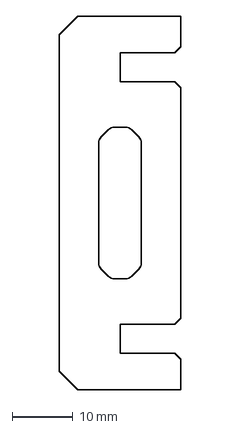
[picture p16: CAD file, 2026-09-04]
ESTRUCTURA 3D CARTON PLUMA/CORTE LASER/SOP. INFERIOR X2.dxf
20.0 x 61.6 mm

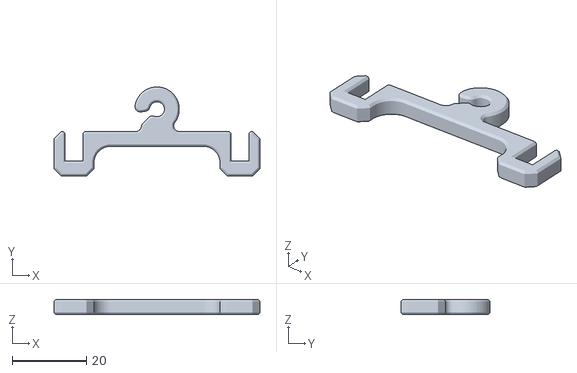
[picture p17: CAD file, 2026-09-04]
ESTRUCTURA 3D CARTON PLUMA/IMPRESION 3D/SOPORTE IMPRESO GLOBO v3.stl
55.5 x 24.0 x 4.00

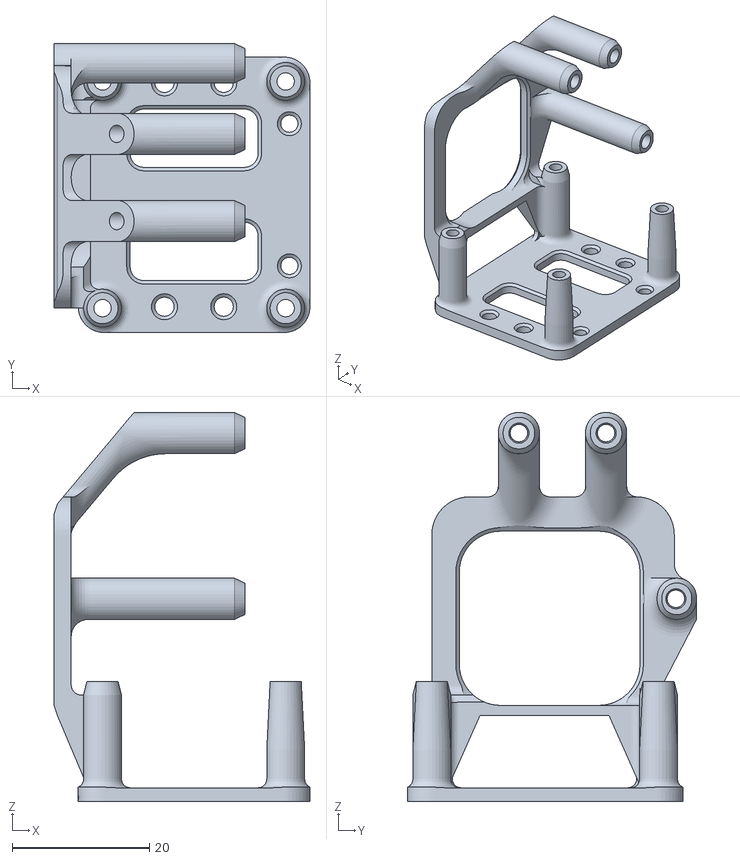
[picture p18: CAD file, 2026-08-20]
ESTRUCTURA 3D CARTON PLUMA/IMPRESION 3D/SOPORTE PLACAS v14.stl
37.3 x 42.1 x 56.7

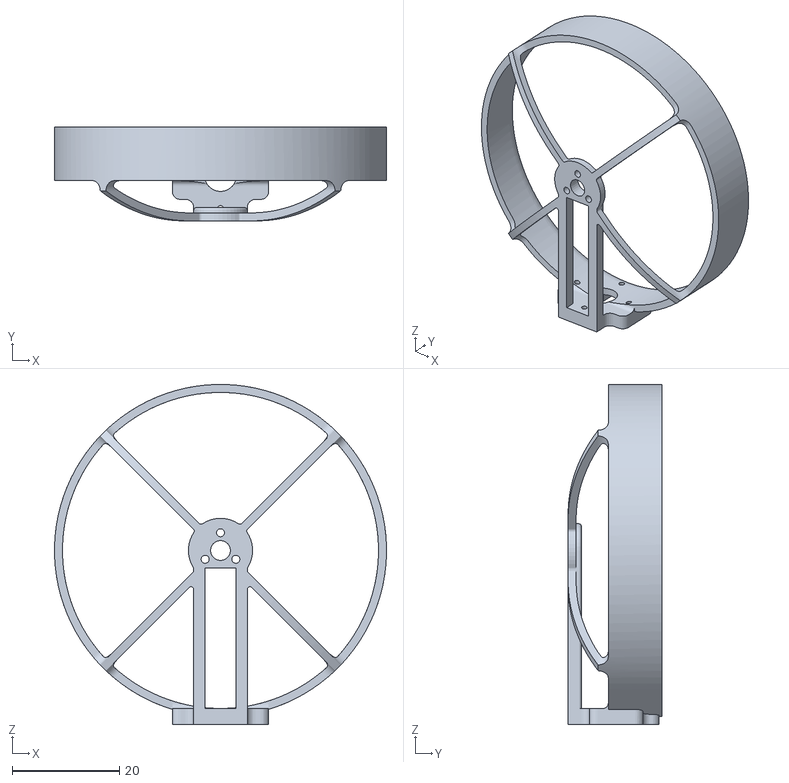
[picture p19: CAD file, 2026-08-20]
ESTRUCTURA 3D CARTON PLUMA/IMPRESION 3D/PROPELLER GUARD v5.stl
62.0 x 17.5 x 63.5

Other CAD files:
ESTRUCTURA 3D CARTON PLUMA/Ensamblaje Blimp CARTON PLUMA.f3z
ESTRUCTURA 3D/FUSION360/1102 BRUSHLESS v3.f3d
ESTRUCTURA 3D/FUSION360/BATERIA v2.f3d
ESTRUCTURA 3D/FUSION360/BRAZO IMPRESO v19.f3d
ESTRUCTURA 3D/FUSION360/ESTRUCTURA 3D v28.f3d
ESTRUCTURA 3D/FUSION360/MINI SERVO v3.f3d
ESTRUCTURA 3D/FUSION360/PLACA NICLA v1.f3d
ESTRUCTURA 3D/FUSION360/PROPELLER CCW v2.f3d
ESTRUCTURA 3D/FUSION360/PROPELLER CW v1.f3d
ESTRUCTURA 3D/FUSION360/PROPELLER GUARD v5.f3d
ESTRUCTURA 3D/FUSION360/SENSOR DE PRESION v1.f3d
ESTRUCTURA 3D/FUSION360/SOPORTE PLACAS v14.f3d

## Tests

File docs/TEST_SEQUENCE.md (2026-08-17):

# Secuencia de pruebas

El firmware nuevo contiene todos los modos; no se reflashea entre P01–P11. La base solo retransmite.

1. **P01** integración de sensores, sin actuadores.
2. **P02** control manual limitado. Verifica signo Fx/Fz/Tz.
3. **P03** lazo de yaw. Aquí se valida también la convención roll/pitch heredada antes de corregirla.
4. **P04** lazo de altura.
5. **P05** yaw + altura.
6. **P06** Nicla raw; obtener `w`/score vs distancia real.
7. **P07** centrado visual sin avance.
8. **P08** un globo.
9. **P09** visita + escape + pérdida obligatoria del objetivo.
10. **P10** dos globos idénticos.
11. **P11** cuatro globos idénticos.

## Seguridad

- D2 se mantiene HIGH y reservado para RST del BNO.
- PWM de servos/motores está deshabilitado al boot.
- ARM requiere comando explícito.
- `SAFE_STOP` desarma y desconecta PWM.
- Brushless tienen límite duro de 0.50 del comando normal.
- El software **no** soluciona posible backfeed USB→VCC→boost→VBAT. Antes de dejar actuadores conectados con batería retirada, medir VBAT con solo USB.

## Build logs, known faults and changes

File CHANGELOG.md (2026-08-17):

# v2 - hardware actual sin ultrasonico

- SensorSuite reducido a BMP390 + BNO085/BNO086 + monitor de bateria D8.
- Nicla Vision pasa a offset 11; arreglo total de sensores = 21.
- Telemetria core usa velocidad vertical en lugar de distancia ultrasonica.
- Codigo GY-US42V2 movido a `legacy/unused_sensors/` y no forma parte del build activo.
- La evitacion de pared heredada en `LevyWalk` queda deshabilitada para evitar interpretar `NICLA_FLAG` como distancia.

# Cambios de esta entrega

- Refactor P01–P11 con un solo firmware y módulos de prueba separados.
- Safe boot: sin auto-arm ni auto-calibración; PWM de actuadores deshabilitado al iniciar.
- ARM/DISARM explícito por `ControlInput.params[10]`.
- Límite duro de brushless: 50% del comando original.
- D2 reservado/HIGH como RST del BNO.
- Nicla offset ajustado a 11 para el hardware actual sin ultrasonico; protocolo balloon 0x40 conservado.
- GY-US42V2 retirado de `SensorSuite`; la evitacion de pared heredada que dependia de `sensors[11]` queda deshabilitada.
- Telemetría independiente por flag a 10 Hz y base genérica `TEL,...`.
- Nueva misión para globos idénticos: SEARCH→APPROACH→VISIT→ESCAPE→WAIT_LOST→SEARCH.
- Snapshot de archivos principales originales en `legacy/`.

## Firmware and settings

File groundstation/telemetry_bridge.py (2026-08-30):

"""
telemetry_bridge.py  -  Puente WebSocket bidireccional para la app Flutter

USO
---
    python telemetry_bridge.py COM5
    python telemetry_bridge.py /dev/ttyUSB0 --port 8765 --dev-token MICLAVESECRETA

Que hace
--------
Abre el mismo BlimpLink que usan run_test.py / simple_control.py para leer
el puerto serial de la base station, reenvia la telemetria a todos los
clientes conectados, permite que clientes autenticados como "dev" manden
comandos de vuelta (armar/desarmar/control directo), y guarda la misma
telemetria en logs/blimp_<timestamp>.csv con el mismo formato que usa
run_test.py (o sea, analyze.py funciona igual con vuelos hechos desde la
app).

No reemplaza ni modifica run_test.py: es un lector/escritor alternativo del
mismo puerto serial. No lo corras al mismo tiempo que run_test.py -- dos
procesos no pueden abrir el mismo puerto serial a la vez.

ROLES: VIEWER vs DEV
---------------------
El PRIMER mensaje que manda cada cliente, apenas conecta, tiene que ser un
mensaje de auth:

    {"auth": {"role": "viewer"}}
    {"auth": {"role": "dev", "token": "MICLAVESECRETA"}}

- Sin mandar auth, o con role="viewer": el cliente SOLO recibe telemetria.
  Cualquier otro mensaje que mande se ignora.
- Con role="dev" y el token correcto (--dev-token al arrancar el bridge,
  default 'changeme' -- CAMBIALO): el cliente puede ademas mandar comandos.
  Si el token no coincide, se lo trata como viewer igual (no se cae la
  conexion, simplemente no tiene permiso de mandar comandos).

Si el auth no coincide, el bridge responde:
    {"auth_ok": true,  "role": "dev"}
    {"auth_ok": true,  "role": "viewer"}   # token invalido -> degradado
    {"auth_ok": false, "error": "primer mensaje debe ser auth"}

TELEMETRIA (servidor -> todos los clientes)
--------------------------------------------
    {
        "t": 1735000000.123,
        "flag": 1,
        "fields": {"height": 1.23, "yaw": 0.41, ...}
    }
Ver LABELS en common/telemetry.py para el set de campos por flag.

COMANDOS (cliente dev -> servidor)
------------------------------------
    {"cmd": "arm"}
    {"cmd": "disarm"}
    {"cmd": "stop"}                      # SAFE_STOP, desarma
    {"cmd": "control",
     "mode": 0, "fx": 0.0, "fz": 0.0, "tx": 0.0, "tz": 0.0,
     "arm": 0, "reload": 0, "reset": 0,
     "aux": {"5": 0.12, "7": 0.08}}       # indices de aux como string

"control" es de bajo nivel: el cliente arma fx/fz/tx/tz/aux a mano, con los
indices crudos que espera ControlInput. Para P03-P11 eso significa conocer
el empaquetado de bits ALT_PACK/YAW_PACK (ver common/control_pack.py) y el
mapa de slots por modo -- exactamente lo que hace run_test.py. En vez de
reimplementar eso en la app, usa los comandos de alto nivel:

    {"cmd": "mission_start", "test": "p08", "height": 0.7,
     "kp": 0.30, "ki": 0.025, "kd": 0.10, "max_power": 15, "slew": 0.18,
     "vis_min_power": 6, "vis_max_power": 10, "vis_deadband_px": 20}

    {"cmd": "mission_update", "test": "p08", ...mismos campos...}

"test" es el mismo string que usarias como argumento de run_test.py
(p03..p11). Los demas campos son EXACTAMENTE los mismos nombres que los
--flags de run_test.py sin guiones (--vis-min-power -> "vis_min_power"),
y los que se omiten usan el mismo default que la CLI (ver
common/control_pack.py:DEFAULT_ARGS). El bridge arma fx/fz/tx/tz/aux con
common.control_pack.build_control_payload(), el MISMO codigo que usa
run_test.py, asi que el resultado es identico bit a bit.

- "mission_start": hace la secuencia completa de armado (igual que
  run_test.py): manda el paquete con arm=1, espera 4.2s a que arme el ESC,
  y despues manda reset=1 con las mismas referencias/ganancias. Uso: boton
  "Iniciar mision".
- "mission_update": NO rearma. Solo reenvia fx/fz/tx/tz/aux con reset=1 --
  para ajustar ganancias en caliente con la mision ya corriendo/armada.

Ambos responden con:
    {"cmd_ok": true, "cmd": "mission_start", "effective": ["...", "..."]}
"effective" son las mismas lineas de texto que run_test.py imprime como
"VALORES EFECTIVOS" (los parametros YA cuantizados que se van a aplicar).

BANCO DE PRUEBAS: P00 (servos) y P00M (motores)
------------------------------------------------
Equivalente de alto nivel a `run_test.py p00` / `p00m`, para el panel de
banco de pruebas de la app. A diferencia de mission_start/update, esta
logica NO pasa por common/control_pack.py (P00/P00M no usan el empaquetado
ALT_PACK/YAW_PACK ni el mapa de slots de P03-P11): son modos crudos con
selector de servo / potencia directa, asi que se arman aca mismo.

    {"cmd": "servo_set", "servo": "both", "angle1": 35, "angle2": 95}
                                                        # servo: '1'|'2'|'both'

Si "servo" es '1' o '2', mueve SOLO ese servo (el otro queda detach, igual
que la CLI). Si es 'both', mueve LOS DOS con sus propios angle1/angle2 --
casi nunca deben ser iguales: los servos van en espejo, asi que el vector
vertical real es 35/95 (no 35/35), avance 120/0, retroceso 0/120 (ver
SERVO*_Z_DEG/FORWARD_DEG/BACK_DEG en firmware/src/app/ControlCommon.h).
Sirve para chequear a mano si el vector de empuje resultante apunta donde
deberia.

    {"cmd": "motor_arm", "servo1": 35, "servo2": 95}

Hace la secuencia completa de P00M: posiciona AMBOS servos con brushless
BLOQUEADOS, espera 1s, y ejecuta la secuencia de ARM del firmware viejo
(throttle minimo ~3.7s y vuelve a 0). Este comando tarda ~5s en responder
a proposito -- recien cuando responde cmd_ok es seguro mandar potencia.
SIN ESTO, motor_power no hace nada (los actuadores siguen desarmados).

    {"cmd": "motor_power", "motor": "both", "power": 10,
     "servo1": 35, "servo2": 95}

Aplica potencia (0..100%) en caliente sobre los servos ya armados por
motor_arm. Hay que seguir mandando los mismos servo1/servo2 en cada
llamada (el firmware no los recuerda entre paquetes de este modo). Para
cortar YA: mandar power=0, o directamente {"cmd": "stop"} (SAFE_STOP,
desarma todo).

Opcional en cualquier comando: "mac": "DC:B4:D9:39:B3:B4" para apuntar a un
robot especifico. Si no se manda, usa ROBOT_MACS[0] de user_parameters.py.

Cada comando recibe una confirmacion LOCAL del bridge (que el byte salio
por el puerto serial), no una confirmacion del firmware -- esa la vas a
ver aparte, en la telemetria normal que sigue llegando (por ejemplo, el
campo "armed" del flag 3 cambiando a 1):
    {"cmd_ok": true, "cmd": "arm"}
    {"cmd_ok": false, "cmd": "arm", "error": "sin permiso (rol viewer)"}
"""

import argparse
import asyncio
import json
import struct
import time
from pathlib import Path

import websockets

from common.link import BlimpLink, mac_to_bytes
from common.telemetry import LABELS, parse
from common.control_pack import NAME_TO_MODE, build_control_payload, make_args
from common.csv_logger import CsvLogger
from user_parameters import ROBOT_MACS

clients: dict[websockets.WebSocketServerProtocol, str] = {}  # ws -> role
serial_write_lock = asyncio.Lock()

# El firmware reporta su modo actual en cada trama del flag 3 (ver
# Telemetry::sendActuators). Lo guardamos aca para que arm()/disarm() no
# tengan que adivinar un modo -- si mandaramos mode=0 a ciegas mientras
# una mision (P08, etc.) esta corriendo, eso fuerza una transicion a
# SAFE_STOP y mata la mision, aunque la intencion era solo armar/desarmar.
last_known_mode = 0


# ============================================================================
# ESCRITURA SIN ESPERAR RESPUESTA
#
# BlimpLink.send()/control() escriben Y ADEMAS leen una linea de vuelta
# (_line(0.4)) para mostrar el ack en consola. Si hacemos eso mientras el
# read_loop de mas abajo tambien esta leyendo el mismo puerto en continuo,
# se pisan: el ack de un comando puede terminar consumido por el lector de
# telemetria (o viceversa), y ninguno de los dos lados ve lo que esperaba.
#
# Por eso aca escribimos DIRECTO al serial, sin leer respuesta. El efecto
# del comando se ve igual en la telemetria normal (por ejemplo "armed"
# cambiando), que ya viaja por el unico lector continuo (read_loop).
# ============================================================================

def _pack_control(mode=0, fx=0, fz=0, tx=0, tz=0, arm=0, reload_=0, reset=0,
                   aux=None):
    p = [0.0] * 13
    p[0] = mode; p[1] = fx; p[2] = fz; p[3] = tx; p[4] = tz
    if aux:
        for idx, val in aux.items():
            p[int(idx)] = float(val)
    p[10] = arm; p[11] = reload_; p[12] = reset
    return p


async def write_control(link: BlimpLink, mac: str, **kwargs) -> None:
    params = _pack_control(**kwargs)
    payload = b'C' + mac_to_bytes(mac) + struct.pack('<13f', *params)
    async with serial_write_lock:
        link.ser.write(payload)


# ============================================================================
# WEBSOCKET: TELEMETRIA (broadcast) + COMANDOS (solo dev)
# ============================================================================

async def broadcast(msg: str) -> None:
    if not clients:
        return
    await asyncio.gather(
        *(c.send(msg) for c in clients),
        return_exceptions=True,
    )


def make_handler(link: BlimpLink, dev_token: str):

    async def handler(ws: websockets.WebSocketServerProtocol) -> None:
        role = None
        try:
            # Primer mensaje OBLIGATORIO: auth.
            first = await ws.recv()
            try:
                msg = json.loads(first)
            except (json.JSONDecodeError, TypeError):
                msg = {}

            auth = msg.get('auth') if isinstance(msg, dict) else None
            if not isinstance(auth, dict):
                await ws.send(json.dumps({
                    'auth_ok': False,
                    'error': 'primer mensaje debe ser auth',
                }))
                await ws.close()
                return

            requested_role = auth.get('role', 'viewer')
            if requested_role == 'dev' and auth.get('token') == dev_token:
                role = 'dev'
            else:
                role = 'viewer'

            clients[ws] = role
            await ws.send(json.dumps({'auth_ok': True, 'role': role}))
            print(f"[bridge] cliente conectado como '{role}' "
                  f"({len(clients)} activos)")

            async for raw in ws:
                if role != 'dev':
                    continue  # viewers no pueden mandar comandos, se ignora

                try:
                    msg = json.loads(raw)
                except (json.JSONDecodeError, TypeError):
                    continue

                cmd = msg.get('cmd')
                mac = msg.get('mac') or (ROBOT_MACS[0] if ROBOT_MACS else None)
                if not mac:
                    await ws.send(json.dumps({
                        'cmd_ok': False, 'cmd': cmd,
                        'error': 'sin MAC (configura ROBOT_MACS)',
                    }))
                    continue

                try:
                    effective = None

                    if cmd == 'arm':
                        await write_control(link, mac, mode=last_known_mode, arm=1)
                    elif cmd == 'disarm':
                        await write_control(link, mac, mode=last_known_mode, arm=-1)
                    elif cmd == 'stop':
                        # STOP si es a proposito un cambio de modo: fuerza
                        # SAFE_STOP y desarma, para cortar cualquier mision
                        # en curso de forma segura.
                        for _ in range(3):
                            await write_control(link, mac, mode=0, arm=-1)
                            await asyncio.sleep(0.05)
                    elif cmd == 'control':
                        await write_control(
                            link, mac,
                            mode=msg.get('mode', 0),
                            fx=msg.get('fx', 0), fz=msg.get('fz', 0),
                            tx=msg.get('tx', 0), tz=msg.get('tz', 0),
                            arm=msg.get('arm', 0),
                            reload_=msg.get('reload', 0),
                            reset=msg.get('reset', 0),
                            aux=msg.get('aux'),
                        )
                    elif cmd in ('mission_start', 'mission_update'):
                        test = msg.get('test')
                        if test not in NAME_TO_MODE:
                            await ws.send(json.dumps({
                                'cmd_ok': False, 'cmd': cmd,
                                'error': f'test desconocido: {test!r} '
                                         f'(usa p03..p11, igual que run_test.py)',
                            }))
                            continue

                        overrides = {k: v for k, v in msg.items()
                                     if k not in ('cmd', 'test', 'mac')}
                        try:
                            control_args = make_args(test, **overrides)
                            fx, fz, tx, tz, aux, effective = build_control_payload(control_args)
                        except (TypeError, ValueError) as e:
                            await ws.send(json.dumps({
                                'cmd_ok': False, 'cmd': cmd,
                                'error': f'parametros invalidos: {e}',
                            }))
                            continue

                        mode = NAME_TO_MODE[test]
                        if cmd == 'mission_start':
                            # Misma secuencia que run_test.py: ARM con el
                            # paquete completo, esperar al ESC, y recien
                            # despues RESET para arrancar limpio.
                            await write_control(link, mac, mode=mode,
                                                 fx=fx, fz=fz, tx=tx, tz=tz,
                                                 aux=aux, arm=1)
                            await asyncio.sleep(4.2)
                        await write_control(link, mac, mode=mode,
                                             fx=fx, fz=fz, tx=tx, tz=tz,
                                             aux=aux, reset=1)

                    elif cmd == 'servo_set':
                        # P00: si servo es '1'/'2', mueve SOLO ese servo (el
                        # otro queda detach). Si es 'both', mueve los DOS a
                        # la vez con SUS PROPIOS angulos -- angle1/angle2
                        # casi nunca son iguales, porque los servos van en
                        # espejo (el vector vertical real es 35/95, no
                        # 35/35; ver SERVO*_Z_DEG en ControlCommon.h).
                        servo = str(msg.get('servo', 'both'))
                        angle1 = float(msg.get('angle1', 35.0))
                        angle2 = float(msg.get('angle2', 95.0))
                        if not (0.0 <= angle1 <= 120.0 and 0.0 <= angle2 <= 120.0):
                            await ws.send(json.dumps({
                                'cmd_ok': False, 'cmd': cmd,
                                'error': 'angle1/angle2 deben estar entre 0 y 120 grados',
                            }))
                            continue
                        selector = {'1': 1.0, '2': 2.0, 'both': 3.0}.get(servo)
                        if selector is None:
                            await ws.send(json.dumps({
                                'cmd_ok': False, 'cmd': cmd,
                                'error': f"servo debe ser '1', '2' o 'both', "
                                         f"recibido {servo!r}",
                            }))
                            continue
                        await write_control(link, mac, mode=NAME_TO_MODE['p00'],
                                             aux={5: angle1, 6: angle2, 7: selector},
                                             reset=1)
                        effective = [f'Servo {servo}: S1={angle1:.0f}° S2={angle2:.0f}°']

                    elif cmd == 'motor_arm':
                        # P00M, paso a paso, igual que run_test.py:
                        #  1) posiciona AMBOS servos con brushless bloqueados
                        #  2) secuencia de ARM del firmware viejo: throttle
                        #     minimo ~3.7s y vuelve a 0 -- ahi si ya se puede
                        #     mandar potencia con motor_power.
                        # A diferencia de la CLI (que usa el tiempo que tarda
                        # el humano en escribir "ARMAR" como colchon), aca
                        # esperamos explicito antes de responder cmd_ok.
                        s1 = float(msg.get('servo1', 35.0))
                        s2 = float(msg.get('servo2', 95.0))
                        if not (0.0 <= s1 <= 120.0 and 0.0 <= s2 <= 120.0):
                            await ws.send(json.dumps({
                                'cmd_ok': False, 'cmd': cmd,
                                'error': 'servo1/servo2 deben estar entre 0 y 120 grados',
                            }))
                            continue
                        await write_control(link, mac, mode=NAME_TO_MODE['p00'],
                                             aux={5: s1, 6: s2, 7: 3.0}, reset=1)
                        await asyncio.sleep(1.0)
                        await write_control(link, mac, mode=NAME_TO_MODE['p00m'],
                                             arm=1, aux={5: s1, 6: s2, 7: 0.0, 8: 0.0})
                        await asyncio.sleep(4.0)
                        effective = [f'Servos en S1={s1:.0f}° S2={s2:.0f}°, ESC armado']

                    elif cmd == 'motor_power':
                        # Actualiza potencia en caliente (mode ya armado por
                        # motor_arm). Sin ARM previo, el firmware ignora la
                        # potencia porque los actuadores siguen desarmados.
                        motor = str(msg.get('motor', 'both'))
                        power = float(msg.get('power', 0.0))
                        s1 = float(msg.get('servo1', 35.0))
                        s2 = float(msg.get('servo2', 95.0))
                        if motor not in ('1', '2', 'both'):
                            await ws.send(json.dumps({
                                'cmd_ok': False, 'cmd': cmd,
                                'error': f"motor debe ser '1', '2' o 'both', "
                                         f"recibido {motor!r}",
                            }))
                            continue
                        if not (0.0 <= power <= 100.0):
                            await ws.send(json.dumps({
                                'cmd_ok': False, 'cmd': cmd,
                                'error': 'power debe estar entre 0 y 100',
                            }))
                            continue
                        m1 = power / 100.0 if motor in ('1', 'both') else 0.0
                        m2 = power / 100.0 if motor in ('2', 'both') else 0.0
                        await write_control(link, mac, mode=NAME_TO_MODE['p00m'],
                                             aux={5: s1, 6: s2, 7: m1, 8: m2})
                        effective = [f'Motor {motor}: {power:.0f}%']

                    else:
                        await ws.send(json.dumps({
                            'cmd_ok': False, 'cmd': cmd,
                            'error': f'comando desconocido: {cmd}',
                        }))
                        continue

                    ok_msg = {'cmd_ok': True, 'cmd': cmd}
                    if effective is not None:
                        ok_msg['effective'] = effective
                    await ws.send(json.dumps(ok_msg))

                except (websockets.exceptions.ConnectionClosed, OSError):
                    # El cliente se corto justo al mandar/recibir la
                    # confirmacion del comando (tipico de celular con la
                    # pantalla apagada o cambiando de app). No es un bug
                    # del bridge, no hace falta traceback.
                    break

                except Exception as e:  # noqa: BLE001 - avisamos cualquier otro fallo al cliente
                    try:
                        await ws.send(json.dumps({
                            'cmd_ok': False, 'cmd': cmd, 'error': str(e),
                        }))
                    except (websockets.exceptions.ConnectionClosed, OSError):
                        break

        except (websockets.exceptions.ConnectionClosed, OSError):
            # Conexion cortada de golpe (Android matando la app en segundo
            # plano, WiFi inestable, etc.) -- normal en un celular, no
            # ensuciamos la terminal con el traceback completo.
            pass

        finally:
            clients.pop(ws, None)
            print(f"[bridge] cliente desconectado ({len(clients)} activos)")

    return handler


# ============================================================================
# LECTURA CONTINUA DEL SERIAL -> BROADCAST
# ============================================================================

async def read_loop(link: BlimpLink, logger: CsvLogger) -> None:
    global last_known_mode
    loop = asyncio.get_event_loop()
    gen = link.lines()

    def next_line():
        try:
            return next(gen)
        except StopIteration:
            return None

    while True:
        line = await loop.run_in_executor(None, next_line)
        if line is None:
            break

        tel = parse(line)
        if tel is None:
            continue

        logger.add(tel)

        labels = LABELS.get(tel.flag, [])
        fields = dict(zip(labels, tel.values))

        if tel.flag == 3 and 'mode' in fields:
            last_known_mode = int(fields['mode'])

        payload = {
            't': time.time(),
            'flag': tel.flag,
            'fields': fields,
        }
        await broadcast(json.dumps(payload))
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

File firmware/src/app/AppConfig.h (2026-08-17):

#pragma once
#include <Arduino.h>

namespace AppConfig {
// PCB real del proyecto
constexpr int SERVO1_PIN = D0;
constexpr int SERVO2_PIN = D1;
constexpr int BNO_RST_PIN = D2;
constexpr int SDA_PIN = D4;
constexpr int SCL_PIN = D5;
constexpr int NICLA_TX_PIN = D6;
constexpr int NICLA_RX_PIN = D7;
constexpr int BATTERY_ADC_PIN = D8;
constexpr int MOTOR1_PIN = D9;
constexpr int MOTOR2_PIN = D10;

constexpr int NICLA_OFFSET = 11;
constexpr int SENSOR_COUNT = 21;

// Potencia original del firmware heredado: 0.0 .. 1.0.
// 1.0 conserva el mismo max_thrust=35 g y la misma conversion a PWM del proyecto viejo.
constexpr float ABSOLUTE_MOTOR_POWER_LIMIT = 1.00f;

// ControlInput.params[]
constexpr int PARAM_MODE = 0;
constexpr int PARAM_FX = 1;
constexpr int PARAM_FZ = 2;
constexpr int PARAM_TX = 3;
constexpr int PARAM_TZ = 4;
constexpr int PARAM_AUX0 = 5;
constexpr int PARAM_AUX1 = 6;
constexpr int PARAM_AUX2 = 7;
constexpr int PARAM_AUX3 = 8;
constexpr int PARAM_AUX4 = 9;
constexpr int PARAM_ARM = 10;
constexpr int PARAM_RELOAD = 11;
constexpr int PARAM_RESET = 12;

// K-Power P0025: 0..120 deg nominales = 900..2100 us.
constexpr int P0025_MIN_US = 900;
constexpr int P0025_CENTER_US = 1500;
constexpr int P0025_MAX_US = 2100;
constexpr float P0025_MIN_DEG = 0.0f;
constexpr float P0025_CENTER_DEG = 60.0f;
constexpr float P0025_MAX_DEG = 120.0f;

enum Mode : int {
    SAFE_STOP = 0,
    P00_MOTOR_POWER_TEST = 8,
    P00_SERVO_CALIBRATION = 9,
    P01_SENSOR_INTEGRATION = 10,
    P02_MANUAL_CONTROL = 11,
    P03_YAW_CONTROL = 12,
    P04_ALTITUDE_CONTROL = 13,
    P05_YAW_ALTITUDE = 14,
    P06_NICLA_RAW = 15,
    P07_VISUAL_CENTER = 16,
    P08_ONE_BALLOON = 17,
    P09_VISIT_ESCAPE = 18,
    P10_TWO_BALLOONS = 19,
    P11_FOUR_BALLOONS = 20,
};

constexpr uint8_t NICLA_BALLOON_MODE = 0x40;
constexpr uint8_t NICLA_GOAL_YELLOW = 0x80;
constexpr uint8_t NICLA_GOAL_ORANGE = 0x81;

constexpr uint32_t CONTROL_LOOP_US = 4000;
constexpr uint32_t TELEMETRY_PERIOD_MS = 100;
}

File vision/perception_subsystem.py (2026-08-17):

# Auto detect the camera type
import sensor
NICLA = 1
OPENMV = 2
board = NICLA
if sensor.get_id() == sensor.GC2145:
    board = NICLA
elif sensor.get_id() == sensor.OV5640:
    board = OPENMV

import time
import micropython
import array
if board == NICLA:
    from pyb import UART, LED
elif board == OPENMV:
    from machine import LED, UART
from machine import I2C
from vl53l1x import VL53L1X
import image
import math
from machine import Pin
import omv
import random
import asyncio
from ulab import numpy as np

# night mode:
if board == OPENMV:
    sensor.ioctl(sensor.IOCTL_SET_NIGHT_MODE, False)

# framesize setup, nicla cannot handle anything above HQVGA
# openmv, on the other hand, is recommended to run with QVGA
FRAME_SIZE = sensor.HQVGA
if board == NICLA:
    FRAME_SIZE = sensor.HQVGA
FRAME_PARAMS = None
if FRAME_SIZE == sensor.VGA:
    FRAME_PARAMS = [0, 0, 640, 480] # Upper left corner x, y, width, height
elif FRAME_SIZE == sensor.HVGA:
    FRAME_PARAMS = [0, 0, 480, 320]
elif FRAME_SIZE == sensor.QVGA:
    FRAME_PARAMS = [0, 0, 320, 240]
elif FRAME_SIZE == sensor.HQVGA:
    FRAME_PARAMS = [0, 0, 240, 160]

# manual white balance - to be used with *get_gains.py* in the repository
# - see RGB gain readings in the console
if board == OPENMV:
    R_GAIN, G_GAIN, B_GAIN = [62, 60, 65]
elif board == NICLA:
    R_GAIN, G_GAIN, B_GAIN = [91, 64, 92]

########## NOTE: MACROS for balloon detection #############
# Grid setup
N_ROWS = 14
N_COLS = 21

random.seed(time.time())
NUM_CELLS = 2
START_ROW = random.randint(0, N_ROWS-NUM_CELLS-1)
START_COL = random.randint(0, N_COLS-NUM_CELLS-1)

# Probablistic filter for balloon detection
FILTER = True
L_MAX = 4
L_MIN = -4

# print the stats in a 3x3 cell - for balloon color data collection
PRINT_CORNER = False
PLOT_METRIC = not PRINT_CORNER

# whether combine detction of green and purple as target balloons
# setting to False makes the detector to ignore colors other than the currently tracked one
COMBINE_TARGETS = False

# Color distribution - From the data analysis on balloon detection
# to be used with
if board == OPENMV:
    COLOR_DATA = {
        "purple": [[23.36438596491228, -39.03035087719298] ,  [[0.0648033747896978, 0.055988642505018865], [0.05598864250501887, 0.058994799618367275]]],
        "green": [[-20.875354509359045, 8.56792399319342] ,  [[0.060236044299697374, 0.04894408879238302], [0.04894408879238302, 0.0646636883366453]]],
        "blue": [[-0.08622366288492707, -21.085143165856294] ,  [[0.405955173972352, 0.11825244006317702], [0.11825244006317703, 0.04203593483634022]]],
        "red": [[35.494601328903656, 32.24958471760797] ,  [[0.24644136648942605, -0.2762493355717791], [-0.2762493355717791, 0.3291565103824226]]]
    } # openmv
elif board == NICLA:
    COLOR_DATA = {
        "purple": [[23.36438596491228, -39.03035087719298] ,  [[0.0648033747896978, 0.055988642505018865], [0.05598864250501887, 0.058994799618367275]]],
        "green": [[-20.875354509359045, 8.56792399319342] ,  [[0.060236044299697374, 0.04894408879238302], [0.04894408879238302, 0.0646636883366453]]],
        "blue": [[13.596253902185223, -33.79474505723205] ,  [[0.13004108243366663, 0.06653979100910323], [0.06653979100910323, 0.04018167036620918]]],
        "red": [[50.173846153846156, 25.426923076923078] ,  [[0.01470976874406989, -0.029273398296275985], [-0.029273398296275982, 0.08279564686512679]]]
    } # nicla


# color detection sensitivities:
# [0]: higher value for more sensitive detection
# [1]: for filtering out uniform colors such as a light source, higher -> less positive detection
# [2]: for filtering out messy background/environment, lower -> less positive detection
COLOR_SENSITIVITY = {
    "purple": [2.0, 3.0, 20.0],
    "green": [1.5, 5.0, 18.0],
    "blue": [1.5, 3.0, 18.0],
    "red": [3.0, 3.0, 24.0]
}

# range of the L channel values that guarantee valid detection
L_RANGE = {
    "purple": [30, 70],
    "green": [10, 80],
    "blue": [5, 40],
    "red": [2, 80]
}
# the minimum value given by a cell that we consider a positive detection
COLOR_CONFIDENCE = 0.3

# target balloon colors {color id: (RGB value for visulization)}
COLOR_TARGET = {"red": (255,0,0)}

# peer blimp color
COLOR_PEER = {} # {"red": (255, 0, 0)}

# parameters for removing noises and neighbor colors
NEIGHBOR_REMOVAL = True
NEIGHBOR_REMOVAL_FACTOR = 10.0
# NEIGHBOR FORMAT: {$neighbor: ($target, RGB value for visulization)}
COLOR_NEIGHBOR = {}


# tracking parameters
MAX_LOST_FRAME_TARGET = 20 # maximum number of frames without a positive balloon detection
                           # with data of the current detection still reported to the controller
MAX_LOST_FRAME_GOAL = 40   # maximum number of frames without a positive goal detection
MOMENTUM = 0.0 # keep the tracking result move if the detection is momentarily lost

# action kernel setup
FILTER_KERNEL = False #TODO (low priority): using LogOdd filter-based kernel
KERNEL_SIZE = 5 # a n x n kernel that summarizes the possibility scores inside to give the most
                # approachable detection, for target balloon detections only
KERNEL_CENTER_EMPH = 3 # how much weight we want the center of the kernel to count
kernel_scale = KERNEL_SIZE ** 2 + KERNEL_CENTER_EMPH - 1
# setting up the kernel matrix
kernel_matrix = []
for i in range(KERNEL_SIZE):
    kernel_row = []
    for j in range(KERNEL_SIZE):
        if i == KERNEL_SIZE // 2 and j == KERNEL_SIZE // 2:
            kernel_row.append(KERNEL_CENTER_EMPH)
        else:
            kernel_row.append(1)
    kernel_matrix.append(kernel_row)

# Performance profiling
PROFILING = False
CRAZY_RANDOM_OPTIMIZATION = False # TODO: not implemented with numpy batch processing yet
OPTIMIZATION_LEVEL = 0.2 # the higher, the faster, the less accurate
RANDOM_DACAY = 0.5*2*OPTIMIZATION_LEVEL # if we skip the detection of a cell, its confidence of a
                                        # positive detection decays exponentially
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

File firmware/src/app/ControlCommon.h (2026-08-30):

#pragma once
#include <Arduino.h>
#include <math.h>
#include <stdint.h>

// ============================================================================
// ControlCommon.h  -  NUCLEO COMPARTIDO DE CONTROL  (v6)
//
// POR QUE EXISTE ESTE ARCHIVO
// ---------------------------
// Antes, P03 (yaw aislado), P04 (altura aislada) y P05 (yaw+altura) tenian
// TRES implementaciones distintas del mismo control, con unidades distintas:
//
//   - P03 sacaba "fraccion de potencia" y mandaba los servos al extremo
//     (bang-bang). No tenia integral.
//   - P04 sacaba potencia de motor con el integral topado en 6% fijo y sin
//     anti-windup.
//   - P05 v5 sacaba un mando normalizado -1..+1 con mixer y anti-windup.
//
// Consecuencia: las ganancias sintonizadas en P03/P04 NO se podian copiar a
// P05. Este header elimina el problema: los tres tests llaman a las mismas
// funciones, con las mismas unidades, los mismos deadbands, los mismos filtros
// y los mismos topes. Lo que sintonizas en P04 vale en P05. Lo que sintonizas
// en P03 vale en P05.
//
//
// UNIDADES (importante)
// ---------------------
//   ALTURA
//     error        : metros
//     kp           : fraccion de empuje por metro   (0.30 => 30% por metro)
//     ki           : fraccion de empuje por metro-segundo
//     kd           : fraccion de empuje por (m/s)
//     salida       : "zDemand" = empuje VERTICAL deseado, 0..maxPower
//
//   YAW
//     error        : radianes
//     kp           : mando por radian               (2.00 => satura a ~29 deg)
//     ki           : mando por radian-segundo
//     kd           : mando por (rad/s)
//     salida       : "yawCmd" normalizado, -1..+1
//     minPower/maxPower : FRACCION DE POTENCIA DE MOTOR (esto no cambia)
//
//
// CAMBIOS DE FONDO RESPECTO A v5
// ------------------------------
// 1) La zona muerta del yaw vive en el ERROR, no en el mando.
//    En v5 el mixer usaba `|yawCmd| > 0.02`. Con kp bajo eso se traducia en un
//    deadband REAL enorme y oculto: con kp=0.08 el yaw no actuaba hasta 14.3
//    grados de error. Ahora el deadband es explicito y configurable en grados.
//
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

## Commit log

2026-08-15 V0.1: modificacion en el script de telemetria, arreglo en parametros de esp32 blimp, data de entrenamiento de nicla vision, configuracion de esp32 base
    [interactive_control.py, main.cpp, perception_subsystem.py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]
2026-08-16 V0.2: Besta de todo el nuevo sistema antes de particionarlo para pruebas desde 0
    [busqueda_metricas.csv]
2026-08-17 V0.3: Actualizacion completa del proyecto blimp, arquitectura modular, P00-P11, vision y documentacion
    [busqueda_metricas.csv]
2026-08-18 Update P05YawAltitude.cpp
    python run_test.py p05 --height 0.3 --yaw-deg 90 --kp 0.20 --ki 0.00 --kd 0.10 --alt-min-power 10 --max-power 15 --slew 0.12 --alt-success-cm 10 --yaw-kp 0.08 --yaw-kd 0.06 --yaw-min-power 7 --yaw-ma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
2026-08-24 V0.4: Base final para competencia con prueba de seguimineto de hasta 4 globos y ajustes en pruebas p03-p11, ajustes en envio y recepecion de telemetria y creacion de socket para obtener datos desde u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
2026-08-30 V0.5: App AeroStock rediseñada, control P00-P11 desde la app, y mixer analitico de avance
    App (blimp_app):
    - Rediseño completo con paleta azul/celeste calibrada sobre los logos reales
    de ESPOL/FIMCP, logo propio de AeroStock (silueta del bicoptero), y pie de
    pagina institucional.
    - Panel de mision (P08-P11) y panel de control (P04/P05) corregidos: el
    protocolo viejo pisaba mode/fx/fz/tx/tz con los valores de ganancia por
    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
2026-08-30 V0.6: README con guia rapida de como compilar y correr todo (CLI y app)
    Agrega una seccion al inicio del README (sin renumerar las secciones
    existentes) con la secuencia completa de arranque: compilar/subir firmware
    y base station, configurar user_parameters.py, y las dos formas de
    controlar el blimp -- por consola (run_test.py) o desde la app AeroStock
    (arrancar telemetry_bridge.py, conectar, tabla de que panel de la app
    equivale a que prueba).
    De paso corrige las 8 referencias a "servo 2 = 85 grados" que quedaban en
    ejemplos y tablas del documento (el valor real es 95 desde el 23/08), y
    aclara que los CSV de logs/ los genera tanto run_test.py como
    telemetry_bridge.py, no solo la CLI.
    Co-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
2026-09-04 V0.7: Bakja al frame de deteccion y velocidad de avance
